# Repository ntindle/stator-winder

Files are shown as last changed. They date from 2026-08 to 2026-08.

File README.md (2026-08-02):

# Stator Winder

Parametric CAD, simulation, and validation tooling for a four-axis flyer
winding machine for small BLDC stators.

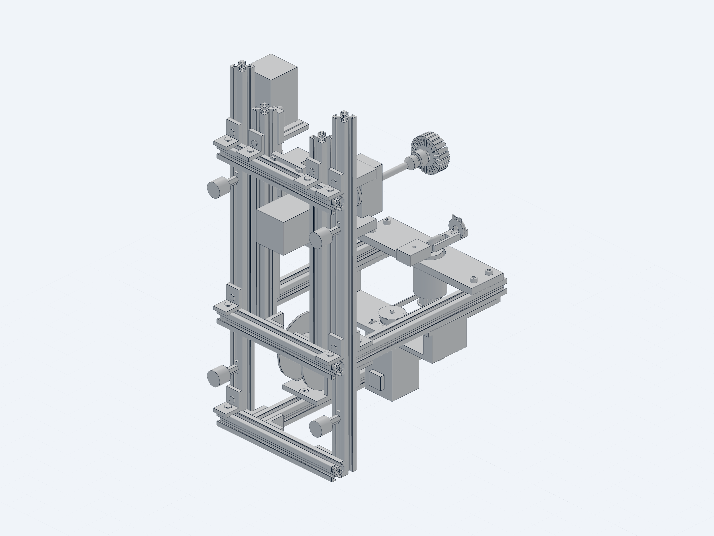
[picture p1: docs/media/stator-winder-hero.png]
Stator winder reference assembly


> [!WARNING]
> This is an engineering research prototype, not a production-ready machine.
> It has not completed physical winding, endurance, electrical-safety, or
> operator-safety qualification. The current release logic intentionally keeps
> hardware motion fail-closed.

The project models the complete mechanism in Python, derives controller
settings from the geometry, captures the real controller's motion contract,
and audits collisions, wire routing, loads, printability, and procurement
readiness before hardware is purchased.

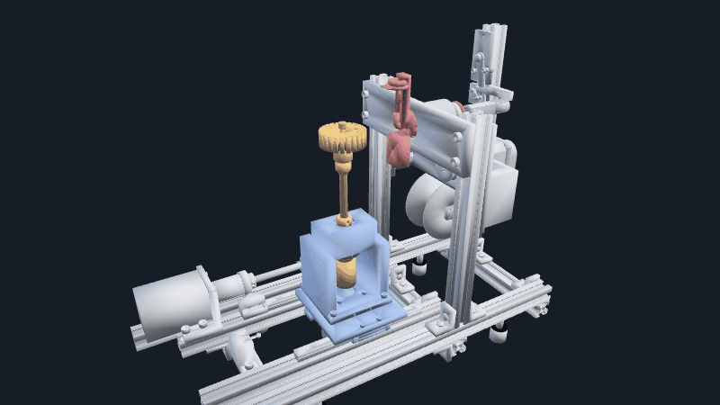
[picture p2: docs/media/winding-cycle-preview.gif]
Simulated winding-cycle preview


_Generated from the captured upstream-motion simulation. This is a mechanism
visualization, not physical-process or production evidence._

<p align="center">
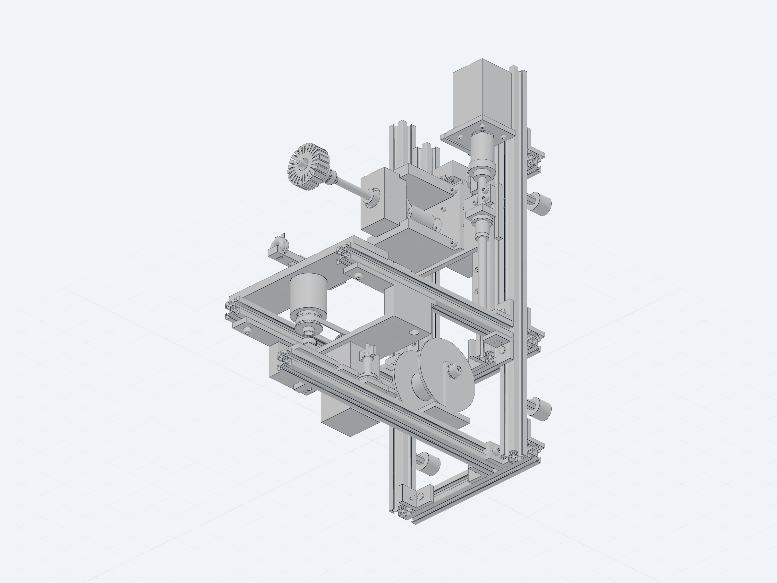
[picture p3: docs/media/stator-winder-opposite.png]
Stator winder drive-side assembly view
  
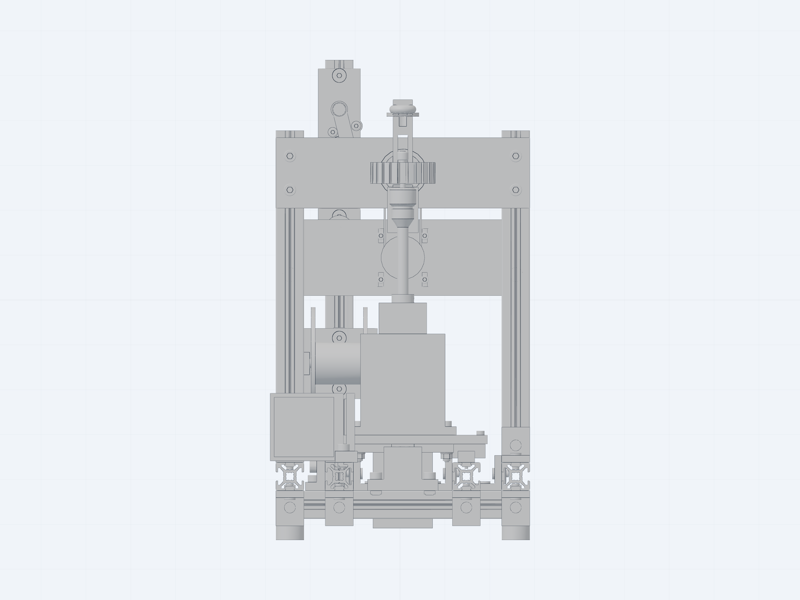
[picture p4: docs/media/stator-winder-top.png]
Stator winder top assembly view
  
</p>

_High-resolution views of the redistributable reference assembly. Purchased
components use project-authored dimensional envelopes._

## Project status

- Parametric machine, tooling, and fixture source is present.
- The controller protocol and upstream motion sequence are captured and tested.
- Extensive rigid-body, conductor-path, manufacturing, and procurement audits
  are implemented.
- The selected rigid geometry has useful simulation evidence, but the complete
  moving conductor path and physical process are not yet qualified.
- The launch matrix remains **0/24 production-authorized configurations**.
- No claim is made that this design is safe to build or operate without an
  independent engineering and safety review.

The detailed working state lives in
[`docs/engineering-status.md`](docs/engineering-status.md), and open release
work is tracked in [`TODO.md`](TODO.md).

## Download and build

The public [`hardware/`](hardware/) package contains a vendor-free reference
assembly, 21 print-oriented STL files with editable STEP counterparts, custom
machining STEP files, the carriage DXF, shop drawings, proof coupon, and order
CSVs. Start with the [`builder guide`](BUILD.md) and review the explicitly
incomplete [`cost status`](COSTS.md) before ordering anything.

The loadable assembly uses project-authored dimensional envelopes for
purchased components. Exact supplier CAD remains optional local verification
material and is not redistributed without a clear license grant.

## Architecture

| Axis | Role | Current mechanical approach |
| --- | --- | --- |
| M0 | Stator carriage | Dual MGN12 rails and a T8x8 lead screw |
| M1 | Stator index | Direct-drive, continuously rotating workholder |
| M2 | Flyer | Belt-driven hollow shaft, balanced arm, and wire guide |
| M3 | Tension | Passive felt drag and spring dancer; motor mount reserved |

The default verification envelope covers 28–65 mm stator OD, 5–20 mm stack
height, 3–8 mm shafts, and 0.20–0.50 mm magnet wire. Those are modeling inputs,
not qualified production limits.

The machine is designed around the command and motion contract of
[`aotenjo-xyz/winder`](https://github.com/aotenjo-xyz/winder). That MIT-licensed
project remains a separate dependency and is not copied into this repository.
The project-owned adapter is deliberately narrow and preserves the upstream
serial protocol.

## Repository map

```text
cad/          parametric mechanism, parts, drawings, and CAD audits
controller/   fail-closed entry point around the separate upstream controller
docs/         requirements, engineering status, and RFQ material
hardware/     loadable alpha build package containing project-owned artifacts
print/        proof-coupon and slicer-profile tooling
sim/          capture, kinematics, collision, conductor, and release audits
bom.csv       purchasing candidates and qualification state
TODO.md       open engineering and release blockers
```

Selected project-owned build artifacts are tracked under `hardware/`. The
broader generated audit tree and locally downloaded supplier models remain
untracked; they are either reproducible evidence or externally controlled
reference assets rather than project source.

## Quick start

Python 3.11 is the currently verified runtime. On Windows PowerShell:

```powershell
git clone https://github.com/ntindle/stator-winder.git
git clone https://github.com/aotenjo-xyz/winder.git
Set-Location stator-winder
py -3.11 -m venv .venv
.venv\Scripts\python.exe -m pip install -r requirements-dev.txt
.venv\Scripts\python.exe -m playwright install chromium
.venv\Scripts\python.exe cad\settings_gen.py --spindle er11
.venv\Scripts\python.exe cad\assembly.py `
  --reference-mode envelope `
  --output out\stator_winder_reference_envelope.step
```

Keep the two checkouts as siblings, or pass `--winder` explicitly to
`controller/run.py` and `sim/capture.py`.

Run the source-only smoke checks:

```powershell
.venv\Scripts\python.exe -m unittest discover -s sim -p "test_controller_adapter.py"
.venv\Scripts\python.exe -m unittest discover -s cad -p "test_settings_gen.py"
.venv\Scripts\python.exe -m unittest discover -s cad -p "test_public_reference_envelopes.py"
```

Many geometry and release tests require supplier CAD cached under
`cad/models/`. Those files are intentionally not redistributed here. See
[`cad/models/README.md`](cad/models/README.md) and the adjacent provenance
reports before running the full suite.

The source-only reference assembly and packaged manufacturing artifacts do not
require that optional exact-model cache.

## Typical workflow

```powershell
# Generate settings from the current geometry
.venv\Scripts\python.exe cad\settings_gen.py --spindle er11

# Export the vendor-free reference assembly and collision links
.venv\Scripts\python.exe cad\assembly.py `
  --reference-mode envelope `
  --output out\stator_winder_reference_envelope.step
.venv\Scripts\python.exe cad\export_links.py --spindle er11

# Optional: with the separately obtained exact supplier-model cache
.venv\Scripts\python.exe cad\assembly.py --reference-mode exact

# Capture the untouched upstream motion stream
.venv\Scripts\python.exe sim\capture.py `
  --controller upstream `
  --settings out\settings.yml `
  -o out\capture\upstream_current_raw.jsonl

# Reconstruct and audit it
.venv\Scripts\python.exe sim\verify_cycle.py `
  --capture out\capture\upstream_current_raw.jsonl `
  --report out\reports\upstream_current_raw_cycle.json `
  --expect-controller upstream
.venv\Scripts\python.exe sim\collide.py `
  --workers 1 `
  --capture out\capture\upstream_current_raw.jsonl `
  --output out\reports\clearance_upstream_raw.json
.venv\Scripts\python.exe sim\wirepath.py `
  --capture out\capture\upstream_current_raw.jsonl `
  --output out\reports\wirepath_upstream_raw.json
```

Several release commands are expected to return nonzero while a safety or
evidence gate remains open. A nonzero result must not be bypassed merely to
produce a green report.

## Origin and third-party material

The mechanical source in this repository was independently parameterized from
the project's requirements. Publicly visible product photos, documentation,
patent publications, and conventional flyer-winder architecture were used to
understand function and failure modes; their images and geometry are not
included.

The separate Aotenjo controller established the compatibility contract. COTS
dimensions and locally cached supplier models were used for fit and collision
work. Because several of those downloads have vendor-only or unclear
redistribution terms, the public source tree excludes all supplier CAD,
datasheets, product photos, converted previews, and community models.

See [`PROVENANCE.md`](PROVENANCE.md) and [`NOTICE.md`](NOTICE.md) for the exact
boundary. Licensing a repository does not grant rights in third-party patents,
trademarks, reference media, or supplier CAD.

## Licensing

- Project software and documentation: [MIT](LICENSE)
- Original mechanical design source: your choice of MIT or
  [CERN-OHL-P-2.0](LICENSES/CERN-OHL-P-2.0.txt)
- Third-party dependencies and locally cached reference assets: their own
  terms; they are not covered by the project license and are not included in
  the public source snapshot

The precise file-scope rules are in [`LICENSES/README.md`](LICENSES/README.md).

Copyright 2026 Nicholas Tindle.

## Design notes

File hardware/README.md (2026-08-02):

# Hardware build package

Everything under this directory is project-authored output selected for the
public alpha build package. It is covered by the repository's mechanical
design license scope in [`../LICENSES/README.md`](../LICENSES/README.md).

The package deliberately contains no supplier or community CAD. Purchased
components in the reference assembly are project-authored dimensional
envelopes. See [`manifests/external-cad.json`](manifests/external-cad.json) for
the optional exact-model cache boundary and [`../BUILD.md`](../BUILD.md) for
the build workflow.

`manifests/build-package.json` records a SHA-256 checksum, size, category, and
source path for every generated artifact in this package.

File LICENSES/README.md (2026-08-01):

# License scope

Copyright 2026 Nicholas Tindle.

This repository uses established licenses without custom license clauses.

## Software and documentation

Project-authored software, tests, configuration, reports, and documentation are
licensed under the [MIT License](../LICENSE).

SPDX expression: `MIT`

## Original mechanical design source

Project-authored mechanical design source—including the Python CAD under
`cad/`, print tooling under `print/`, fabrication descriptions, and original
generated design outputs—is dual-licensed. You may use it under either:

- the [MIT License](../LICENSE); or
- the [CERN Open Hardware Licence Version 2 - Permissive](CERN-OHL-P-2.0.txt).

SPDX expression: `MIT OR CERN-OHL-P-2.0`

The CERN license is particularly suited to making and sharing physical
products from design source. The copy in this repository is the unmodified
definitive CERN-OHL-P-2.0 text.

## Third-party material

Third-party dependencies and locally cached reference files are governed by
their own terms and are not covered by either project license. The intended
public source snapshot excludes supplier CAD, datasheets, product media,
archives, and unlicensed community models. See [`NOTICE.md`](../NOTICE.md) and
[`PROVENANCE.md`](../PROVENANCE.md).

If a third-party artifact is present in a local working copy, its presence does
not make it MIT- or CERN-OHL-licensed.

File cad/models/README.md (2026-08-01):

# External CAD cache

This directory is a local cache boundary, not a redistributable model library.

The project uses exact supplier and catalog models for interface checks where
their geometry materially affects fit or collision results. Most of those
files do not carry an open redistribution license. They are therefore ignored
by Git and must be obtained directly by each user under the source's current
terms.

The project-authored Python generators, JSON provenance manifests, and Markdown
verification reports remain versioned. Consult `upgrades/*.report.md`,
`upgrades/*.source.json`, `bom.csv`, and `NOTICE.md` for:

- expected local filename;
- supplier and exact part number;
- source URL;
- known license or terms boundary;
- authoritative interface dimensions; and
- SHA-256 checksum where one was recorded.

Do not substitute a similarly named model without rerunning the dimensional,
placement, collision, and load audits that depend on it.

The absence of a supplier file should fail the exact-model audit or select an
explicit parametric-envelope path. It must never silently create a claim that
the exact purchased component was verified.

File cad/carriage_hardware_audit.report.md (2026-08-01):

# Carriage hardware audit — Goal 1

Date: 2026-07-10  
Scope: MIC6 carriage plate, MGN12H block fasteners, spindle tower, M1 motor,
T8 nut/bracket, rear endstop flag, and the M0 fixed-end support.

## Result

The isolated corrected candidates pass all eight deterministic tests.  Four
real positive-volume faults were reproduced and removed.  The M1 motor stack
was also checked explicitly and is already correct: the current two-millimetre
underside pocket leaves a four-millimetre printed roof under all four heads.

| source-level Boolean check | measured pre-fix | corrected candidate |
|---|---:|---:|
| four inner MGN12H M3 heads vs spindle tower | 275.158 mm³ | 0.000 mm³ |
| rear flag M4 washers/nylocs vs printable flag | 294.614 mm³ | 0.000 mm³ |
| lower two T8 washer/nyloc stacks vs bracket foot | 79.108 mm³ | 0.000 mm³ |
| printable flag vs M0 fixed-end mount | 12.000 mm³ | 0.000 mm³ |
| M1 head-bearing material, four 0.10 mm annular probes | 6.504 mm³ | 6.504 mm³ |

Run:

```powershell
.\.venv\Scripts\python.exe cad\test_carriage_hardware_audit.py
```

Observed: `Ran 8 tests ... OK`.

## Exact shared patch table

1. `cad/printed.py:spindle_tower`

   Subtract four axis-Y cylinders, Ø6.4 and 3.25 mm deep from the MIC6 mating
   face, at machine X/Z `(-35,85)`, `(-35,105)`, `(35,85)`, `(35,105)`.
   Start the overshooting tools at `plate_top_y - 0.5`.  The ISO 4762 M3 head
   is Ø5.68 x 3.00, so this provides 0.36 mm radial print allowance and leaves
   a 2.75 mm roof, above the 2.4 mm minimum wall.  Keep all eight M3x10 block
   screws.  Do not countersink the MIC6 plate.

2. `cad/printed.py:nut_bracket`

   Replace the current full-width 8 mm foot with:

   - a 2.4 mm-high web at `x=-84..-60`, `y=plate_top..plate_top+2.4`,
     `z=85..109`;
   - an 8 mm-high local M4 bearing rail at `x=-84..-72`,
     `y=plate_top..plate_top+8`, `z=92..112`;
   - Ø7.2 access channels through only the web, `z=85..92`, centered on the
     T8 flange's 225° and 315° holes.

   Keep the main T8 wall at `z=77..85` and its four Ø3.2 through-holes.  This
   gives every washer a full bearing face while clearing the two lower nylocs.

3. `cad/printed.py:m0_fixed_end_mount`

   Trim the support foot's X maximum from `-35` to `-38`.  This gives the
   moving flag 2.0 mm lateral clearance at every M0 pose.  The M5 center at
   `x=-45` retains a 4.3 mm edge ligament outside its Ø5.4 clearance hole.

4. `cad/hardware_placements.py:carriage_occurrences`

   Split front/rear tower under-head stack datums:

   - front row (`z=64`): washer `y=plate_bottom=-192.00`, nyloc `y=-192.90`;
   - rear row (`z=126`): washer `y=FLAG_BOTTOM_Y=-198.00`, nyloc `y=-198.90`.

   Keep ISO 4762 M4x20 at the front and M4x25 at the rear.  After the ISO 7089
   0.9 mm washer and ISO 10511 5.0 mm nyloc, visible thread is 1.75 mm front
   and 0.75 mm rear.

5. `cad/hardware.py` and `cad/hardware_placements.py`

   Change the four T8 flange screws from ISO 4762 M3x16 to M3x18.  Keep head
   plane `z=73.2`, set washer plane `z=85.0`, and set nyloc start `z=85.55`.
   The stack is 3.8 mm flange + 8.0 mm printed wall + 0.55 mm washer + 4.0 mm
   nyloc = 16.35 mm, leaving 1.65 mm visible thread.  The tip ends at `z=91.2`,
   0.8 mm before the local M4 rail begins.

No shared patch is required for M1: keep ISO 4762 M3x10 x4, head plane
`y=-179.65`.  The existing four-millimetre roof leaves 6.0 mm thread
engagement in the motor.

## SendCutSend and datum preservation

The MIC6 source, 1:1 DXF, outer contour, 14 round holes, motor window, and T8
relief remain byte-for-byte eligible for the existing through-cut preflight.
No countersink, counterbore, tapping, or second-side machining is introduced.
Measured plate volume remains 61,747.022181 mm³ in 6.35 mm ALUMIC6-250.

The stator/spindle datum is unchanged: axis `X=0`, home `Z=95`; MIC6 bottom
`Y=-192.00`, top `Y=-185.65`.  No bearing seat, tower M4 coordinate, motor
face, or MGN12H coordinate moves.

## Intended-contact and dynamic-fit mapping

The following relationships must be whitelisted as documented fits/contacts,
not ignored generically:

| pair/stack | intent |
|---|---|
| plate / tower | printed tower seats on MIC6 top face |
| plate / rear flag | flag seats on MIC6 bottom face |
| MGN screw / plate / tapped block | head bearing, clearance pass, 3.65 mm engagement |
| tower screw / tower / plate [/ flag] / washer / nyloc | complete front/rear clamp stack |
| bracket M4x25 / local rail / plate / washer / nyloc | complete bracket clamp stack |
| T8 M3x18 / flange / wall / washer / nyloc | four equivalent, wrench-accessible stacks |
| M1 M3x10 / four-millimetre roof / motor | head bearing plus 6.0 mm tapped engagement |
| inner-race spacer / outer-race spacer | explicit dynamic fit exemption; 0.20 mm concentric radial clearance, zero positive-volume overlap |
| lower inner spacer / lower DIN 472 ring | explicit dynamic fit exemption; about 0.60 mm concentric radial clearance, zero positive-volume overlap |

The last two exemptions are appropriate because the general 2 mm dynamic
clearance policy cannot apply across a bearing race stack.  They should remain
conditional on a zero-positive-volume Boolean check; do not make a blanket
spindle/carriage exemption.

## Artifact note

This work adds an inspection module, tests, and this report only.  It does not
export or modify a primary STEP, so CAD snapshot/viewer handoff is intentionally
deferred to the production assembly regeneration after the shared patch is
applied.

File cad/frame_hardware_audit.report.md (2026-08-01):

# Static frame hardware source-BREP audit

OpenCascade common-volume booleans on the authored build123d solids; STL/FCL meshes are not used.

## production 15-HBKT plus custom-shoe layout (bracket bodies)

- Brackets: 15
- Broad-phase candidate pairs: 5
- Positive-volume pairs: 0
- Allowed thread/T-slot engagements: 0
- Forbidden collisions: 0

## independently normalized 15-HBKT plus custom-shoe layout (HBKT bodies)

- Brackets: 15
- Broad-phase candidate pairs: 5
- Positive-volume pairs: 0
- Allowed thread/T-slot engagements: 0
- Forbidden collisions: 0

## Custom rear-post left shoe

- Shoe/cross common volume: 0.000000 mm3
- Shoe/post common volume: 0.000000 mm3
- Gap to left base rail: 1.000000 mm
- Nearest repositioned HBKT gap: 1.000000 mm
- Floor bore minimum ligament: 3.300 mm
- Upright bore minimum ligament: 5.300 mm
- Floor head minimum edge margin: 1.640 mm
- Upright head minimum edge margin: 3.640 mm
- Scallop back wall: 3.400 mm
- Scallop-to-upright-bore ligament: 2.500 mm
- Forbidden positive-volume pairs: 0

Allowed positive volumes are limited to the documented T-slot envelope:

- `rear_post_left_shoe_floor_m5x12` / `cross_rear`: 8.329693 mm3, `tslot_passage_envelope`
- `rear_post_left_shoe_floor_tnut` / `cross_rear`: 141.887304 mm3, `tslot_capture`
- `rear_post_left_shoe_upright_m5x12` / `rear_post`: 8.329693 mm3, `tslot_passage_envelope`
- `rear_post_left_shoe_upright_tnut` / `rear_post`: 40.200000 mm3, `tslot_capture`

## Exact disposition

- Replace `frame_bracket_rear_post_left` and its four stack occurrences with the custom 14 mm-floor shoe and two M5x12/HNTA5-5 stacks. A 25 mm HBKT leg cannot fit the 15 mm X corridor.
- The requested shoe fastener centers initially failed: floor screw / upright shoe = 62.827142 mm3 and the two screw envelopes = 12.713730 mm3. Add the OD9.2 scallop y=-219.2..-213.2 and move the upright axis-X stack from y=-211 to y=-208.
- Reposition `rear_base_L`, `mid_base_L/R`, and `front_base_L/R` to their cross front faces/upper-member undersides with `x=(1,0,0), y=(0,0,1), z=(0,-1,0)`.
- Reposition `front_stringer_L/R` the same way at origins `(-45,-225,170)` and `(45,-225,170)`.
- The proposed 16th front-Z rear-post HBKT is rejected: exact common volume with the rear post is 1810.303324 mm3.
- `post_L_front` / T8 has zero common volume. It is a tangent manufacturing-risk contact, not an allowed engagement; add a 2 mm corner relief if tolerance clearance is required.

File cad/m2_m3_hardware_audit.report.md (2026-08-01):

# M2/M3 source-level hardware audit

Scope: current build123d/OpenCascade solids from `printed.py`, `cots.py`,
`hardware.py`, and `hardware_placements.py`.  The audit is isolated and does
not modify shared machine geometry.  It samples the dancer from -3.0 to +5.5
degrees at 0.25 degree increments and checks candidate repairs with exact BREP
Boolean intersections.

Result: **62/62 exact checks pass**.  Audit regression tests: **7/7 pass**
(**26/26** in the focused flyer/hardware suite).
Machine-readable evidence is generated at
`out/reports/m2_m3_hardware_audit.json`.

## Required shared-source patches

1. **M2 mount low-head access** (`printed.m2_motor_mount`)
   - Current left/right low M5x12 heads each embed in the join block by
     236.1413 mm3; the high pair is clear.
   - Subtract two OD10 axial tool/head tunnels at x=+-80, y=-72,
     z=-103..-66.  The z=-66 end is the existing screw bearing plane.
   - Candidate overlap is 0 for all four screws, the mount remains one solid,
     and 5363.81 mm3 is removed.

2. **Flush all eight rear-post base screws** (`printed` + hardware schedule)
   - Replace the spool/felt/dancer/entry M5x12 socket heads with ISO 10642
     M5x12 countersunk screws at the same axes and top plane z=-164.
   - Add OD10/OD5.4, 90 degree countersinks, depth 2.3, to all eight base
     holes.  This uniform choice avoids four separate head-access rules.
   - Current dancer-head/arm overlap reaches 128.157 mm3.  One entry head
     reaches 35.739 mm3.  Felt heads overlap each OD20 backing/pad stack by
     55.734 mm3 per side and also intersect the printed boss.
   - Candidate overlap is zero.  Dancer arm axial clearance is at least
     1.000 mm throughout the complete stop range; stop axes do not move.

3. **Entry lower-right moving-stack relief** (`printed.entry_bracket`)
   - Subtract the box x=-38.5..-27, y=-22..-7, z=-171..-163.5.
   - Current moving pulley nyloc overlap is 5.5423 mm3 and the last three
     rear shims each overlap by 1.4874 mm3.  The candidate has zero overlap;
     minimum repaired gaps are 2.7447 mm for the nyloc and 2.2655 mm for the
     shims.
   - The bracket remains one solid; 255.001 mm3 is removed.  The wire passage,
     fixed spring bridge, base screw axes, and both dancer stop centers remain
     unchanged.

4. **Flush moving spring-anchor head** (`printed.dancer_arm` + schedule)
   - Current M2x16 socket head overlaps the entry base by 10.4331 mm3.
   - Replace it with ISO 14581 M2x16 and cut an OD4.8/OD2.4 90 degree rear
     countersink, 1.2 mm deep, top plane z=-163, on the existing moving-anchor
     axis.  The 2.5 mm arm retains a 1.3 mm floor.
   - Candidate screw/arm overlap is zero, the arm remains one solid, and its
     minimum entry-bracket gap is 1.000 mm across the full sweep.

5. **M2 internal running clearances** (`assembly`/`printed`)
   - Change the outer-race spacer ID20 to ID22 while retaining OD27.8 and
     length 11.  Exact inner/outer-spacer gap rises from 1.000 to 2.000 mm.
   - Change the flyer-block through-running bore from OD25 to OD26.  Exact
     block clearances become: pulley 2.500 mm, pulley heat-set insert
     2.240 mm, pulley M3 screw 2.428 mm.
   - These are rotating clearances, not intended-contact whitelist pairs.

6. **Felt stud usable thread** (`hardware` + placement)
   - Replace M4x50 with M4x55, same rear datum z=-170.
   - Current thread is only 0.0867 mm proud of the wingnut; candidate is
     5.0867 mm proud.
   - Candidate clearance is 3.400 mm to the conservative OD2 wire model and
     37.779 mm to the exact belt solid.

7. **Counterweight clamp stack** (`hardware_placements`)
   - The three 0.55 mm M3 washers contact each other exactly, but the screw
     bearing plane is 0.55 mm ahead of the stack (exact solid distance
     0.3706 mm because of the head edge).
   - Move only the M3x12 screw origin from z=-11.8 to z=-12.35.  The candidate
     washer/head contact is zero-gap and zero-volume.

8. **Counterweight structural attachment** (`printed.flyer_arm`)
   - The old boss/collar joint had 0.000 mm3 volumetric overlap and depended
     on one coincident rear face.  The two Ø3.3 holes at x=+-6, y=-32 were
     unloaded trim bores, not fasteners, and made the attachment ambiguous.
   - Both trim bores are removed.  An integral PETG web spans x=+-7,
     y=-25..-8.45, z=-28.8..-20.  Exact overlap is 55.357 mm3 into the hub
     collar and 1643.683 mm3 into the counterweight boss; the finished flyer
     arm remains one solid.
   - The web stays 2.400 mm outside the Ø12.1 shaft passage, has 2.200 mm
     clearance to the stationary flyer block, and the complete rotating arm
     retains its existing 2.000 mm minimum block clearance.
   - The one real counterweight axis remains x=0, y=-25.  The M3 screw spans
     the full 4.300 mm McMaster 94459A130 insert; its intended heat-set
     interference is 4.210 mm3.  The three washers are the only tuning stack.
   - The solid boss outer radius is 42.4 mm, still inside the tip-guide sweep.
     Integrated balance is -0.5 g-mm residual (0.00 N rounded at 300 RPM);
     M2 simulation-duty torque margin remains 2.36x.

## Verified stacks and intended contacts

- Spool: OD8 axle has positive clearance through bracket and drum; both
  washers seat against their ears and the right nyloc seats against its
  washer.  No geometry change is required.
- Felt: fixed backing/pad, moving pad/backing, spring/thrust washer, and
  thrust washer/wingnut are zero-gap, zero-volume contacts.  The two pads have
  a 0.500 mm rigid-model wire gap.
- Flyer heat-set inserts: positive overlap is intentional plastic
  displacement, not a collision.  Exact embeds are 5.5953 mm3 for each arm
  insert, 15.7158 mm3 for the pulley insert, and 4.2102 mm3 for the
  counterweight insert.
- Screw shanks in clearance holes must have zero positive volume.  Threaded
  screw/nut or screw/insert pairs may be tangent in the simplified BREP.
- Screw-head/washer bearing interfaces must be zero-gap and zero-volume.
- Dancer stop sleeve/arm contact is allowed only at the specified -3.0 and
  +5.5 degree endpoints; no positive-volume embedding is allowed.
- Inner/outer M2 spacers and flyer clamp hardware/flyer block are running
  clearance pairs and must not be added to an intended-contact whitelist.

All added material is localized to the counterweight web/boss and was checked
explicitly against the shaft passage, stationary flyer block, and rotating
envelope.  The longer felt stud was also checked explicitly as reported above.

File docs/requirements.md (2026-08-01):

# Derived Requirements — 4-Axis Stator Flyer Winder

Source of truth: `winder` repo @ `6039b33` (2026-06-13), read in full. This sheet is derived from
`src/winding.py`, `src/position.py`, `src/utils.py`, `src/constants.py`, `scripts/main.py`,
`scripts/ws.py`, `simulation/node_3d.gd`, `settings-example.yml`, `tests/dev-*.yml`.
GOAL.md is the parent spec. **The software is the fixed contract; geometry must serve it.**

## 1. Protocol contract (serial, host → controller)

| Command | Meaning |
|---|---|
| `M{id}A{value}\n` | Absolute position target, **radians**, float rounded to 3 decimals. Fire-and-forget (no ack; host paces with `sleep()` and position polling). |
| `M{id}P\n` | Position query → response `M{id}P{value}` (radians). Host busy-polls M2 during winding (~30 Hz). |
| `ESTOP\n` | Stop all motors. |

Sent value = model-space target × `direction` sign (per-axis bool in settings) × `m2_gear_ratio`
(M2 only; code constant in `src/constants.py`, currently 50/50 = 1.0 — **not** in settings.yml).
Motion model assumed by the software's own simulator: constant-velocity slew toward target at the
per-axis `velocity` (rad/s) from settings; no acceleration model. Firmware must track **multi-turn
absolute position** on M1 and M2 (M2 accumulates roughly ±7,600 rad over one full 24-slot 50-turn cycle;
M1 zero drifts cumulatively via shaft wraps).

## 2. Kinematic architecture (confirmed by Godot scene mapping)

Machine frame: **Z** = flyer rotation axis (horizontal), **Y** = up.

- **M0 (linear):** translates the stator carriage (with M1 unit) along Z. Godot: `stator.position.z = −M0 + const`.
- **M1 (rotary):** rotates the stator about the **vertical Y axis** — stator shaft is held vertical,
  one tooth points horizontally along Z toward the flyer. Godot: `stator.rotation.y = −M1 + π/2`.
  Unlimited rotation both directions (no cables to the rotating side).
- **M2 (rotary, continuous):** flyer arm spins about Z, coaxial with M0 travel. Godot: `arm.rotation.z = M2`.
  Wire enters through hollow shaft from rear (−Z side), exits at tip eyelet.
- **M3 (torque):** wire tension between spool and hollow shaft. Values are normalized torque
  (`wind_torque: 0.04`, `pull_wire_torque: 0.15`), voltage-mode. `dont_move_m3: true` supported →
  passive tensioner is legitimate for v1.

Winding geometry: the presented tooth's radial axis is parallel to Z; the flyer wraps wire around
the tooth neck; M0 traverse during winding spreads turns **along the tooth length** (radial
direction of the stator), not along stack height.

## 3. M0 coordinate semantics (settings.yml quirks included)

Upstream example values (radians): `wind_range_start=−25.5 < wind_range_end=−14.0` <
rotating `=end+6.0=−8.0` < init zero `=end+9.0=−5.0` < home `0`.

- **More negative = deeper insertion toward/through the flyer plane. Home (absolute 0) = fully retracted = load/unload pose.**
- `m0_zero = M0.end_to_zero + wind_range_end` (init pose after `init_position()`).
- Rotating position `= M1.end_to_rotating_position + wind_range_end` — **note: this key lives under
  the `M1:` section of settings.yml even though it is an M0 target.** The settings generator must respect this.
- During a winding pass M0 slews `start → end → start` once (ease-out-sine on M2 progress,
  re-targeted every π of M2 travel). `ease-out-sine` path has **no range clamp** in
  `position.py` — generated ranges must be self-consistent (`start < end`).
- Transmission ratio (rad→mm) is ours to define and document. Baseline: T8×8 lead screw ⇒
  **1.2732 mm/rad** (upstream's numbers are consistent with this: wind range 11.5 rad ≈ 14.6 mm,
  home-to-wind-end 14 rad ≈ 17.8 mm, indexing retract 6 rad ≈ 7.6 mm).

## 4. M1 / M2 motion semantics the mechanism must survive

- Tooth indexing: `M1 = m1_zero − idx·(2π/N)` (counter-clockwise tooth order), N = slot count (12/24/36 supported today).
- Shaft wrap (`wind_wire_around_shaft`, between each of the 3 phases): current upstream applies an
  **absolute** M1 target derived from `m1_zero`, then permanently mutates `m1_zero` and `m2_zero`.
  From the actual indexed starting poses in the canonical 24-slot raw capture, the completed
  physical deltas are **1.375000 turns** and **2.791667 turns**, not two and two.  The digital twin
  must reproduce those exact raw deltas as evidence, and the mechanism must clear their complete
  swept envelope, but that does **not** make them acceptable winding motion: parent `GOAL.md`
  explicitly requires two full turns at each inter-phase maneuver.  An independent settings and
  fixed-transmission proof shows neither can map both raw deltas to two physical chuck turns while
  preserving 24-slot indexing.  Normal-GOAL release therefore remains fail-closed until an
  unmodified upstream revision restores a relative `current_position ± 4π` target (or the user
  explicitly changes the software-contract authority).
- Flyer parking state machine (`Motor2State`): TOP (12 o'clock), BOTTOM (6 o'clock), each ±
  `angle_to_prevent_collision` (1.0 rad ≈ 57.3° in every shipped config). All six park states occur.
- One winding pass = `turns` (50 in the current default and raw capture) full revolutions + up to 1.5 extra revs for entry/exit
  repositioning (±π wire-side flips, ±1–2 rad park offsets).

## 5. Collision-critical poses (drives the interference test matrix)

1. **Indexing:** M0 at rotating position (stator retracted only ~7.6 mm behind wind-end), M1
   sweeping up to 2π, flyer parked at any of the 6 park states. Rotating stator teeth + shaft stub
   vs. parked arm, eyelet, and wire run.
2. **Wire-side flip, stator partially inserted:** `set_motor2_wire_position()` rotates M2 up to
   2.0 rad with M0 at `wind_range_end`.
3. **Post-pass park, stator fully inserted:** `prevent_collision()` rotates M2 ±1.0 rad with M0
   still at `wind_range_start` (deepest).
4. **`move_wire_to_right_position()` (fires at tooth 16 of 24n22p):** M2 sweeps **π + 1.0 rad with
   the stator fully inserted** at `wind_range_start`. Strongest flyer-vs-stator clearance case.
5. **Shaft wrap:** M0 at rotating position and flyer at TOP ±1 rad.  Collision coverage includes
   both the intended two-full-turn maneuver and the larger current raw 2.791667-turn sweep; the
   wire path from eyelet down to the shaft must clear the arm and chuck throughout.  Passing this
   mechanical envelope cannot waive the separate upstream command-stream failure.
6. **Full winding sweep:** flyer 360° swept volume vs. inserted stator (all M0 wind-range depths),
   chuck body below the stator, and carriage/frame. The chuck column below the stator sits inside
   the flyer's swept cylinder region — arm reach/shape and tip circle must be proven against the
   chuck at max stator OD and min chuck standoff.
7. **Load/unload:** all axes at absolute 0 (`back_to_zero()`), operator access to the chuck.
8. Winding start from 6 o'clock (`starts_at≠0` restart path): M2 moves π from zero with M0 at init zero.

## 6. Velocity / duty data (motor sizing inputs)

| Axis | Config velocity | Peak in cycle | Notes |
|---|---|---|---|
| M0 | **20 rad/s** generated | 20 rad/s ≈ 25.5 mm/s | Settings-only timing fix; reaches deep winding start before the first raw M2 command |
| M1 | **20 rad/s** generated | 20 rad/s | Reaches both current raw absolute targets inside 1.5 s; a corrected two-turn relative target would finish in 0.628319 s. Velocity changes timing only and cannot repair the wrong raw displacement. |
| M2 | 20 rad/s | 20 rad/s = **191 RPM** | `fast_winding` commands ~10.5 rad/s (≈100 RPM), then a single long move runs at the 20 rad/s cap. Design target **≥ 300 RPM (31.4 rad/s)** per GOAL. |
| M3 | torque mode | 0.04–0.15 norm. | Passive in v1 (`dont_move_m3`) |

## 7. Digital-twin fidelity requirements

- Drive the **unmodified** software (`scripts/main.py -s` piped, or `Wind(cfg, simulation=True).continuous_winding()`)
  and capture the command stream via `WINDER_LOG_LEVEL=DEBUG` (env override built into `utils.init_logger`) —
  every `move_motor` logs the exact serial command with a millisecond timestamp.
- Twin must replicate: constant-velocity slew model, `m1_zero`/`m2_zero` drift, Motor2State ±offsets,
  and the M0↔M2 coupled traverse. Official validation run uses **real sleeps** (unmodified timing);
  iteration runs may cap `sleep` at 0.35 s exactly as the repo's own test suite does.
- `scripts/ws.py` hardcodes `settings.yml` in CWD and streams 60 fps interpolated positions —
  our generated settings.yml must also live at repo root for the Godot/WebSocket path to work.

## 8. Flags / contradictions vs GOAL.md

1. **Shaft-wrap contradiction -- release blocker:** GOAL and the code comment require two physical
   M1 turns, but untouched upstream `6039b33` completes 1.375000 and 2.791667 turns.  The regression
   entered at upstream `8e7904a`.  Zero, direction, velocity, `starts_at`, M0/M2 settings, all 48
   canonical electrical pattern equivalents, and any one fixed affine M1 transmission have been
   exhausted; none can make both maneuvers two turns without also breaking tooth indexing.  The
   twin reproduces the stream and geometry is validated against its larger sweep, but normal-GOAL
   DoD remains **FAIL_CLOSED**.  No adapter or local upstream patch is applied.  The smallest
   documented upstream correction is to command the queried live M1 position ± 4π.
2. **Layering limitation, not a software-contract contradiction:** untouched upstream hard-codes
   `ease-out-sine`.  With the current linear T8 transmission it matches the deterministic
   diagnostic honeycomb schedule only 6/2400 placement states and contains zero/sub-wire-diameter
   radial pitch near the traverse reversals.  That means the simulator cannot claim exact layer
   order or neatness; `GOAL.md` explicitly leaves those tension/contact outcomes to hardware
   qualification.  It does **not** by itself require a synchronized guide or nonlinear M0
   transmission.  Production authorization still requires the raw-cycle wire path to distinguish
   intended workpiece/copper contact from steel or hardware contact and to prove a continuous
   centreline bend radius of at least 3 mm.
3. **R3 workpiece-route input gap:** tight conformity to the lined default tooth corner is only
   R0.23876 and cannot satisfy the literal 3 mm rule. Earlier retractable-shroud, R58/R64 review-arm,
   and aggregate-former studies are historical design lanes, not the selected authority. The current
   rev6 architecture uses two M0-following/M1-static active-sector PEEK guides on an outboard
   coil-bypass aluminum yoke plus rotating short-leadin PEEK caps. It passes all 2400 default-job
   terminal loci and the complete rigid raw-motion sweep, without claiming deterministic layer
   order. The flexible guide-to-workpiece conductor family between states, both exact two-turn shaft
   wraps, sag/snags/abrasion, and the 24-case launch envelope remain fail-closed. `StatorSpec` also
   does not define the finished motor's available rotor/end-bell axial cavity, so finished-motor fit
   remains a separate measured constraint.
4. GOAL says software drives ~100 RPM — true for the stepped `fast_winding` phase, but the long
   move to target runs at the **velocity cap = 191 RPM** with shipped configs. The ≥300 RPM
   mechanical target still gives ≥1.57× headroom over the cap; keep the cap in generated settings ≤ our rating/1.5.
5. GOAL describes `angle_to_prevent_collision` as clearing the flyer "during indexing" — the code
   also uses it **doubled** (wire-side flip) and combined with π **while the stator is fully
   inserted** (pose 4 above). Our clearance validation must cover those stronger cases, not just indexing.
6. `end_to_rotating_position` lives under `M1:` in settings.yml despite being an M0 target (§3) —
   generator must follow the quirk, not "fix" it.
7. `m2_gear_ratio` is a code constant, not a settings key: if our flyer is belt-driven with a
   non-1:1 ratio, the **firmware** (out of scope) or a 1:1 belt must absorb it. **Decision: design
   flyer drive as 1:1 belt** so the shipped constant stays valid.
8. Winding configs exist for 12, 24, 36 slots — mechanism must not assume 24 (index angle is 2π/N).

## 9. Fixed design decisions derived above

- M0 baseline: T8×8 lead screw (1.2732 mm/rad), MGN12 rail, home switch at retracted end,
  ~100 mm usable travel.  The rejected inverse-sine/two-track studies do not veto this direct-linear
  mapping; it remains the production candidate while the independent raw-cycle R3/contact wire-path
  gate is open.
- M1: vertical hollow-free chuck axis, motor under carriage, unlimited rotation; ER11 for measured Ø3–7 mm shafts and the separate `shaft8` socket holder only for Ø8.00 mm.
- M2: hollow-shaft flyer with selected Rev-D L79 OD10/ID6-to-OD12/ID9 shaft geometry, stock D10 NBK P30 flyer pulley, conditional D5+BNW motor P30, 210-3GT-6 belt at exact 30T:30T, and six balance trims. OD28–65 is a verification matrix (90 mm remains parametric); 0/24 launch certificates currently pass, so no envelope corner is production-authorized.
- M3: passive dancer + adjustable felt tensioner, 1–10 N, motorized-spool-ready mount, `dont_move_m3: true` in generated settings v1.

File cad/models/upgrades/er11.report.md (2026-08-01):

# ER11 C8 collet chuck — high-fidelity model upgrade report

**Part:** C8-ER11A-100L straight-shank collet chuck (Ø8 mm shank × 100 mm,
ER11-A clamping nut) + ER11 collet
**Deliverables:** `er11_c8_hifi.py`, `er11_c8_hifi.step` (this directory)
**Date:** 2026-07-08
**Replaces (envelope):** `cad/cots.py::er11_chuck_c8` — 3 stacked cylinders
(nut Ø19 × 19, head Ø18 × 16, shank Ø8 × 100, Ø8.2 bore).

---

## 1. STEP search result — no legitimate no-login file found

A downloadable STEP was searched for first:

- **TraceParts / vendor CAD:** ER11 nut and C8-ER11A holder pages exist but
  gate CAD downloads behind account login.
- **GrabCAD / 3DContentCentral:** login-walled — skipped per task.
- **GitHub CNC projects:** hits are STLs / renders, no dimensioned STEP of a
  C8-ER11A-100L holder with an ER11-A nut under a redistributable license.
- **Rego-Fix / vendor sites:** publish **dimensioned drawings** (used below)
  but not free STEP of this exact holder.

Conclusion: no legitimate no-login STEP exists for this exact SKU, so a
**high-fidelity parametric build123d model** was built from cited drawings.

---

## 2. Sources / drawings cited

| # | Source | Used for |
|---|---|---|
| S1 | Rego-Fix *ER System Product Catalog* (us.rego-fix.com RFTC_ER_Catalog) and *ER Spannzangen-Masse* technical drawing (RFAG_TD_ER…) | ER system originator; ER11 nut OD, thread, collet 8° taper geometry |
| S2 | tools-n-gizmos ER Collet Nut spec table (tools-n-gizmos.com/specs/ER_Collet_Nut.html) | ER11 nut: OD 19 mm, L ≈ 11.3–13 mm, thread M14×0.75; A vs mini distinction |
| S3 | MariTool ER11 collet nut product data (maritool.com) | ER11 nut OD 0.748″ = 19 mm, thread M14×0.75, external hex |
| S4 | HHIP / uxcell / Genmitsu / Qjaiune **ER11-A** clamping nut product data | ER11-**A** nut: OD 19 mm, **height 13 mm (19 × 13/14 D×H)**, M14×0.75, 17 mm hex |
| S5 | DIN 6499 / ISO 15488-B ER data — CGTK ER table (cgtk.co.uk/metalwork/data/er), Sikka, CNCollets, Somma (DIN 6499) | ER11 collet: OD 11.5 mm, length 18 mm, **8° taper**, thread Ø14 × 0.75, min bore length 17 mm, clamp 1–7 mm |
| S6 | Amazon / BigaMart **C8-ER11A-100L** product listings | Ø8 straight shank, 100 mm, ER11 (1–7 mm), body ≈ Ø16 behind nut |

Notes on the ER11-A nut: it is the **standard "A" (Ausführung A) nut**,
OD **19 mm**, thread **M14 × 0.75** — distinct from the **ERM11 mini** nut
(OD 16 mm, M13 × 0.75). Sources give the nut height as 11.3–14 mm; **13 mm**
(the most common ER11-A "19 × 13" D×H figure, S4) was used. The real nut has
a light hex/spanner flat for tightening; the model captures the **stepped /
waisted Ø16→Ø19→Ø16 revolved profile** (the dominant collision envelope) and
omits the shallow wrench flats (they sit inside the Ø19 max envelope).

---

## 3. Dimension table — cited vs modeled vs measured

Measured = thin-slab section of the exported STEP (build123d), printed by the
source's `__main__`.

| Feature | Cited (source) | Modeled | Measured (STEP) |
|---|---|---|---|
| ER11-A nut OD (max) | 19.0 mm (S2–S4) | Ø19.0 waisted | **19.00 mm** |
| ER11-A nut waist / collar OD | ~16 mm (Ø16–19 stepped, S1/S4) | Ø16.0 | Ø16 chamfer collars |
| ER11-A nut height | 13 mm (S4; 11.3–14 range) | 13.0 mm | z = 0 … −13 |
| Nut thread | M14 × 0.75 (S2–S5) | plain Ø14 cyl | **14.00 mm** |
| Chuck body / head OD | ~16 mm (S6) | Ø16.0 | **16.00 mm** |
| Shank OD | Ø8 h6 (S6) | Ø8.0 | **8.00 mm** |
| Shank length param | 100 mm (S6) | `shank_len=100` | tip z = **−135.00** |
| Collet OD (large end) | 11.5 mm (S5) | Ø11.5 cone | internal |
| Collet length | 18 mm (S5) | 16 mm cone | internal |
| Collet taper | 8° half-angle (S1/S5) | 8.0° cone | internal |
| Collet seat bore | Ø8.2 (project) | Ø8.2, ~25 mm deep | **8.20 mm** |

**Bounding box (measured):** X −9.50…+9.50, Y −9.50…+9.50, **Z −135.00…0.00**
(19.00 × 19.00 × 135.00 mm). Single closed solid, volume ≈ 9 978 mm³.

### Drop-in frame contract (verified)
- axis **+Z**; nut **TOP face at z = 0.000** ✓
- shank extends **−Z**, Ø8 tip at **z = −135.000** (= −(35 + shank_len)) ✓
- Ø8 shank geometry **identical below z = −35** to the crude model → the two
  608ZZ spindle bearings that grip the shank seat unchanged ✓
- overall XY/Z bounding box **identical** to the crude envelope (Ø19 × 135) ✓

### Deliberate fidelity note — the bore is a seat, not a through-bore
The task says "Ø8.2 through-bore", but a Ø8.2 (r 4.1) bore run the full length
would be **larger than the Ø8.0 (r 4.0) shank and erase the shank entirely**.
The real holder has a **solid Ø8 shank**; the Ø8.2 is the **collet seat**. So,
exactly like the crude model (whose bore was only 26 mm long), the bore stops
in the head (z = +1 … −24) and the Ø8 shank stays solid. Measured bore Ø8.20.

---

## 4. CLEARANCE-CONSTRAINT FLAG CHECK

Validated envelope constraints (from `cad/params.py`):
`chuck_nut_r = 9.5` mm, `chuck_nut_len = 19.0` mm (nut + collet nose),
`grip_gap = 3.0` mm (stator bottom face → nut top face).

| Constraint | Envelope limit | Researched / measured | Verdict |
|---|---|---|---|
| **Nut outer radius** | ≤ **9.5 mm** | **9.500 mm** (Ø19 nut) | ⚠️ **AT LIMIT — ZERO MARGIN** |
| Nut + nose axial length below stator | ~**19 mm** | **13 mm** nut, nose flush at z=0 → 13 mm (16 mm incl. 3 mm grip_gap) | ✅ PASS (6 mm spare) |

### ⚠️ FLAG — radial: nut is EXACTLY at the 9.5 mm envelope limit
The real **ER11-A nut is Ø19 mm → outer radius 9.500 mm**, which **equals**
the validated `chuck_nut_r = 9.5` mm envelope exactly. It does **not exceed**
the limit, but there is **ZERO radial clearance margin**:

- Any ER11-A nut that runs to the high side of tolerance (some are listed at
  Ø19.x mm) **would exceed** the 9.5 mm envelope and break the validated
  clearance constraint for the M1 indexing sweep.
- If more radial margin is needed, an **ERM11 mini nut (Ø16 → r 8.0 mm)**
  gives 1.5 mm; note it needs an ERM-threaded (M13 × 0.75) chuck body.
- **Recommendation:** verify the outer diameter of the actual purchased nut.
  Many economy ER11-A nuts measure Ø18 mm (r 9.0, +0.5 mm margin); premium
  balanced nuts run a full Ø19.

### ✅ Axial: better than the crude envelope
The faithful ER11-A nut is **13 mm** tall, not the 19 mm the crude envelope
reserved. Axial space below the stator improves by ~6 mm; the `chuck_nut_len`
= 19 mm figure in `params.py` is **conservative** (safe, slightly loose).

---

## 5. How to regenerate

```
.venv/Scripts/python cad/models/upgrades/er11_c8_hifi.py
```
Exports `er11_c8_hifi.step` and prints the verification block in §3–§4.
`er11_chuck_c8(shank_len=100.0)` is the drop-in factory (matches the
`cots.er11_chuck_c8` signature and local frame).

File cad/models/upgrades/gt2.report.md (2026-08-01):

# GT2 code-CAD upgrades — geometry references & verified measurements

Two pure code-CAD upgrades for the winding-machine flyer (M2) drive, authored
with build123d 0.11.1 and exported/validated with the project venv
(`.venv/Scripts/python`, Python 3.11.9). Neither existing project file was
modified; these are additive drop-in upgrades.

| file | function | STEP export |
|---|---|---|
| `cad/models/upgrades/gt2_profile.py` | `gt2_pulley(teeth=40, bore_d=12.0, width=10.0, flange_r_rear=14.5, flange_r_front=11.5, hub_len=7.5, hub_r=10.0)` | `gt2_pulley_40t_b12.step` |
| `cad/models/upgrades/gt2_belt.py` | `gt2_belt_loop(center_a=(0,0), center_b=(0,-60), pd=25.46, width=6.0)` | `gt2_belt_200.step` |

Both files also expose `gen_step()` (skill/CI compatible) and a `__main__`
that re-exports the STEP and prints the measurements below.

---

## TASK A — Real GT2 tooth-profile printed flyer pulley

Upgrades `cad/printed.py:flyer_pulley()`, which modeled the 40T GT2 pulley as a
smooth cylinder at the pitch diameter (Ø25.46). This module cuts the **real GT2
2 mm curvilinear tooth** while preserving the printed part's exact mounting
contract (flyer-tube clamp).

### GT2 2 mm geometry references (cited)

- **Pitch** `p = 2.000 mm`; **pitch diameter** `PD = teeth·p/π`.
  40T → `PD = 80/π = 25.4648 mm` (matches the printed part's 25.46).
- **Pitch Line Differential** `PLD = 0.254 mm` — published Gates PowerGrip GT2
  value; the belt pitch line sits 0.254 mm radially **outside** the pulley
  tip circle, so the pulley **outside (tip) diameter**
  `OD = PD − 2·PLD = 24.957 mm` (the standard ~24.9–25.0 mm figure for a 40T
  GT2 pulley).
- **Tooth (groove) depth** `= 0.75 mm` → `root Ø = OD − 2·0.75`.
- **Arc-based tooth** (the task's accepted GT2 arc construction). Each tooth is
  a fully **G1-tangent alternating chain** of two circular-arc types:
  - convex **land-tip arc**, radius `r_tip = 0.555 mm` (published GT2 tip
    radius), centred on the tooth axis at radius `OD/2 − r_tip`;
  - concave **valley arc**, radius `r_val`, centred over the groove at radius
    `root_r + r_val`.
  `r_val` is solved (bisection) from the external-tangency condition
  `|C_tip − C_valley| = r_tip + r_val`, so tip and valley arcs meet tangentially
  at the flank inflection. **For 40T this gives `r_val = 0.4151 mm`.** The full
  face is 40 tip arcs + 40 valley arcs → the characteristic rounded GT2 profile
  (confirmed in the top-view snapshot).
- The related **1.38 mm** GT2 figure is the *belt body thickness* (used in Task
  B), not a pulley-cut dimension.

> Note on the arc construction: this is a documented arc **approximation** of
> the Gates GT2 2 mm profile (not the licensed Gates involute-of-arc point
> table). It is dimensionally correct at the controlling values (pitch, PLD,
> OD, root, depth 0.75, tip radius 0.555) and prints/meshes as a valid GT2
> tooth; use a licensed profile if exact Gates conformance is required.

### Mounting contract preserved (mirrors `printed.py:flyer_pulley`)

- Bore **Ø12.05** (Ø12 nominal + 0.05 diametral clamp clearance) on the axis.
- Radial **M3 clamp hole** (Ø3.4) through the hub wall (−Y).
- **Rear flange r14.5** (Ø29), **front flange r11.5** (Ø23),
  **hub r10.0** (Ø20), hub length 7.5, flanges 1.5 thick each.

### Local frame

Authored **part-local** (unlike `printed.py`, which is authored in machine
coordinates). Axis +Z: toothed body `z 0..width`; rear flange `z −1.5..0`;
front flange `z width..width+1.5`; hub `z width+1.5..width+1.5+hub_len`.
To place at the printed part's machine location (body `z −93.5..−83.5`,
`params.py:pulley_z`) translate by `Pos(0,0,−93.5)`.

### Measured (from the exported solid / tooth wire sampling)

```
pitch diameter PD          : 25.4648 mm
valley arc radius r_val    : 0.4151 mm  (tip arc r = 0.555 mm, depth = 0.75 mm)
OUTER tooth diameter (OD)  : 24.9568 mm   [calc 24.9568]   (expect ~24.9–25.0) ✓
ROOT diameter              : 23.4568 mm   [calc 23.4568]
rear flange diameter       : 29.0000 mm   (r14.5)
front flange diameter      : 23.0000 mm   (r11.5)
hub diameter               : 20.0000 mm   (r10.0)
bore diameter              : 12.0500 mm
part bbox z                : −1.500 .. 19.000 mm
```

`inspect refs --facts`: single valid part, 90 faces / 255 edges, bounds
±14.5 (flanges) in X/Y, z −1.5..19.

---

## TASK B — Modeled GT2 belt loop

Closed-loop belt solid: two arcs wrapping the two equal (40T) pulley pitch
circles + two tangent straight runs. Tooth detail omitted; a uniform 1.38 mm
band — a visual + collision-conservative envelope.

### References / construction

- **Belt body thickness `= 1.38 mm`** — published Gates GT2 / 2GT overall belt
  thickness; here the radial band thickness, laid symmetrically about the pitch
  line (pitch radius ± 0.69 mm) so the pitch stadium is the solid's
  mid-surface.
- Two **equal** pitch circles → the belt path is a **stadium (racetrack)**: two
  half-circles of radius `pd/2` joined by straight runs of length = centre
  distance `CD`.
- **Belt PITCH length** `= 2·CD + π·pd`.
  `pd=25.46, CD=60` → **`199.985 mm` ≈ a standard 2GT-200 belt (100 teeth)**,
  matching the machine's 200-2GT choice at the 60 mm centre distance
  (`params.py:m2_motor_axis_y = −60`, "belt center distance 60 → 200-2GT").

### Local frame (as required)

Loop generated in the **XY plane**, extruded **+Z over 0..width**. The machine's
belt plane is `z −93.5..−83.5` in machine coordinates (`params.py:pulley_z`); to
place, map local `z 0..width` onto that band (e.g. `Pos(0,0,−93.5)` with the
belt/pulley width in use). `center_a`/`center_b` are the pulley axes in this
local XY plane.

### Measured (from the exported solid)

```
pulley pitch diameter pd   : 25.4600 mm
centre distance CD         : 60.0000 mm
belt body thickness        : 1.3800 mm
computed PITCH length      : 199.9849 mm  (2·CD + π·pd)  → 2GT-200 ✓
belt teeth (pitch_len/2)   : 99.99  (→ 100T)
OUTER perimeter (measured) : 204.3203 mm   [calc 204.3203]
INNER perimeter (measured) : 195.6496 mm   [calc 195.6496]
bbox                       : x ±13.42,  y −73.42..13.42,  z 0..6
```

The **pitch length 199.985 mm** is the belt spec length (mid-surface). The
solid's literal outer/inner perimeters (204.32 / 195.65) bracket it by the
±0.69 mm half-thickness. `inspect refs --facts`: single valid part, 10 faces.

---

## Verification performed

- Ran both modules with `.venv/Scripts/python` → STEP exports written to
  `cad/models/upgrades/`.
- Regenerated STEP + CAD Viewer GLB/topology via the CAD skill
  `scripts/step` (`SOURCE.py=OUTPUT.step` pairs).
- `scripts/inspect refs --facts` on both STEPs → `ok: true`, single valid
  solids, bounds as tabulated.
- `scripts/snapshot` iso + top views: pulley shows 40 rounded GT2 teeth, both
  flanges, hub with radial M3 clamp hole; belt shows the closed stadium band.

## Caveats

- The GT2 tooth is a dimensionally-correct **arc approximation**, not the
  licensed Gates point profile (see note above).
- The belt is a smooth band (no teeth) — a collision/visual envelope, not a
  meshing-accurate belt.
- Both parts are **part-local**; the mapping to machine coordinates is
  documented above and in each module docstring. Existing project files are
  unchanged.
```

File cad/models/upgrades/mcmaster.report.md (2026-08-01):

# McMaster-Carr STEP upgrade for T8x8 lead screw + flange nut

Date: 2026-07-08
Scope: replace the simplified `t8_p2_*` CAD placeholders with real McMaster-Carr STEP
models for a **T8x8 lead screw (8 mm dia, 8 mm lead, 4-start)** and its matching flange nut.

---

## Bottom line (read this first)

1. **McMaster-Carr does not sell a T8x8 lead screw.** There is no screw in the McMaster
   catalog that is simultaneously **8 mm diameter AND 8 mm lead (travel/turn)**. This was
   verified directly against McMaster's live catalog filters (evidence below). The task's
   premise — "pick the correct 8 mm / 8 mm-lead variant from the fast-travel family around
   98935A" — cannot be satisfied because that variant does not exist at McMaster.
     - The part number in the task hint, **98935A**, is not a resolvable product page today
       (McMaster's item-presentation endpoint returns HTTP 500 for it).
2. **No STEP file could be downloaded.** Independent of the part-selection problem, McMaster's
   authenticated CAD download could not be persisted to disk in this browser-automation
   environment (details in "STEP download attempts" below). The direct CAD URL returns
   **403 Forbidden** to any un-cookied client (PowerShell and WebFetch both confirmed).
3. **No STEP files were fabricated.** Per instruction, nothing was invented. The requested
   `t8_screw_mcmaster.step` / `t8_nut_mcmaster.step` files are intentionally **absent** — a
   genuine McMaster T8x8 STEP does not exist to download.

**Recommendation:** keep the existing simplified `cad/models/parts/t8_p2_*` geometry (it is
dimensionally correct for an 8 mm screw), or source a true Tr8x8 STEP from a trapezoidal-screw
vendor / the `step.parts` catalog. See "Recommendation" at the end.

---

## What was requested vs. what McMaster stocks

| Attribute | Requested (T8x8) | Available at McMaster? |
|---|---|---|
| Shaft/major diameter | 8 mm | Only with **1.5 / 2 mm lead** (single-start). No 8 mm lead. |
| Lead (travel/turn) | 8 mm | Only on **4 mm / 5 mm shaft** screws (8-start ultra-precision). |
| Thread starts | 4 | McMaster's 8 mm-lead screws are **8-start**, not 4. |
| Length | ~200 mm | 8 mm-lead screws max out at **150 mm**. |
| Thread form | metric rounded trapezoidal | yes (both families are "Metric Rounded Trapezoidal") |

The two requirements (8 mm diameter, 8 mm lead) live in **two mutually exclusive** McMaster
product families. No single part bridges them.

---

## Catalog investigation (evidence)

McMaster metric lead screws: <https://www.mcmaster.com/products/lead-screws/>

Filter used to isolate every 8 mm-lead screw:
`/products/lead-screws/component~lead-screw/travel-distance-per-turn~8-mm/`
→ **Result: exactly one family, 4537N** (Metric Fast-Travel Ultra-Precision).
   Available shaft diameters in that result set: **4 mm and 5 mm only**; thread starts: **8**;
   thread size: **M4**.

Cross-checks:
- `thread-type~metric-rounded-trapezoidal/shaft-diameter~8-mm/` → **0 products** (filter resets).
- `thread-type~metric-trapezoidal/component~lead-screw/` → family **7549K**, all **single-start**,
  travel per turn 2/3/4/5/7 mm (no 8 mm lead, no 4-start).
- `thread-type~metric-trapezoidal/shaft-diameter~8-mm/` → **0 products**.

Conclusion: an 8 mm-diameter / 8 mm-lead / 4-start trapezoidal screw is **not in the catalog**.

---

## Closest McMaster parts (real part numbers + specs, from the McMaster datasheets)

### Option A — closest on LEAD (8 mm lead), wrong diameter
McMaster "Metric Fast-Travel Ultra-Precision Lead Screws and Nuts" (this is the "fast-travel"
family the task pointed at). **8 mm lead, but M4 / 4–5 mm diameter, 8-start.**

- **Screw 4537N151** — <https://www.mcmaster.com/4537N151/>
  17-4 PH stainless; thread **M4 × 1 mm**, **8 thread starts**, **8 mm travel/turn (lead)**,
  speed ratio 8:1; shaft diameter **5 mm**; one coupling end (Ø9.5 mm × 15.5 mm); length **150 mm**;
  fully threaded; ultra-precision.
- **Flange nut 4537N208** — <https://www.mcmaster.com/4537N208/>
  PEEK, flange nut with wear-compensating internal O-ring (anti-backlash); thread **M4 × 1 mm**,
  **8 starts**, 8 mm lead; body Ø **0.406″ = 10.31 mm**; length **31/64″ = 12.30 mm**;
  flange **3/4″ = 19.05 mm** wide × **13/32″ = 10.32 mm** high × **1/8″ = 3.18 mm** thick;
  ~$83.89 each. (Datasheet marketed for 3D-printing / robotics.)

  Note: the nut's *body* diameter (10.31 mm) happens to be close to the T8 hobby-nut body
  (~10.2 mm), but its **bore is M4 (~4 mm)**, so it will NOT fit an 8 mm screw.

### Option B — closest on DIAMETER (8 mm), wrong lead
McMaster "Ultra-Precision" metric trapezoidal, single-start. **8 mm diameter, but 1.5 mm lead.**

- **Screw 7549K55** — <https://www.mcmaster.com/7549K55/>
  4140 alloy steel; thread **M8 × 1.5 mm**, **single start**, **1.5 mm travel/turn**,
  Metric Rounded Trapezoidal; length **100 mm**; ~$23.68 each. (Longer lengths and an M8 × 2 mm
  variant exist in the same 7549K / related families.) A matching M8 nut is offered alongside.

Neither option is a functional drop-in for a T8x8.

---

## Verification — measured vs. expected (build123d 0.11.1)

The requested `*_mcmaster.step` files do not exist, so there was nothing new to import. Instead
the project's **existing simplified** models were measured to establish the real "expected"
geometry, and the McMaster closest-part figures are quoted from the McMaster datasheets.

`import_step` + `bounding_box()` on the existing placeholders:

| Feature | Expected (T8x8 hobby target) | Existing simplified model (measured) | McMaster 4537N151/208 (datasheet) |
|---|---|---|---|
| Screw major diameter | ~8 mm | **8.000 mm** ✓ (plain Ø8 cylinder) | ~4 mm (M4)  ✗ |
| Screw lead / start | 8 mm / 4-start | n/a (smooth cyl, no thread) | 8 mm / **8-start**  ~/✗ |
| Screw length | ~200 mm | **200.000 mm** ✓ | 150 mm  ✗ |
| Nut flange diameter | ~22 mm | **20.0 mm** (~) | 19.05 mm flange width  (~) |
| Nut flange bolt circle | ~16 mm, 4× M3 | not modeled as discrete holes | not an M3/4-hole hobby pattern |
| Nut body diameter | ~10.2 mm | (flange dominates bbox; ~body n/a) | **10.31 mm**  ✓ |
| Nut overall length | ~15 mm | **24.0 mm** height | 12.30 mm |

Existing-model raw measurements:
- `t8_p2_lead_screw_l0200_simple.step`: bbox **8.000 × 8.000 × 200.000 mm**, volume 10 053 mm³
  (a smooth Ø8 rod — note it is labeled "p2" = 2 mm pitch but is modeled without threads).
- `t8_p2_flange_nut.step`: bbox **20.000 × 20.000 × 24.000 mm**, volume 6 334 mm³.

(The task's "expected" nut values — 22 mm flange, 16 mm bolt circle, 4× M3, 10.2 body, 15 length —
describe the generic hobby "KFL/anti-backlash T8 flange nut," which is not a McMaster product.)

---

## STEP download attempts (what was tried, what blocked it)

Browser automation *was* available (Chrome/Edge extension) and the McMaster site was reachable,
but downloads could not be captured:

1. **McMaster SPA never reaches `document_idle`** (persistent tracking/polling; the `trk.aspx`
   tracker was returning 503). Consequence: the extension's screenshot / `read_page` / native
   `click` tools all time out (45 s) on McMaster pages. All page reading had to be done through
   `javascript_tool` (synchronous DOM reads only).
2. The correct CAD flow was driven via JS: format selector expanded → **"3-D STEP"** selected →
   the download anchor's href resolved to
   `https://www.mcmaster.com/mvC/Library/CAD2/20260103/4F55AEFB/4537N151_Fast-Travel Ultra-Precision Lead Screw.STEP`.
3. **Programmatic anchor `.click()`** issued the request, but the network log shows it stuck at
   **`statusCode: pending`** indefinitely (the SPA context stalls the CAD stream); no file saved.
4. **Opening the CAD URL in a fresh tab (top-level navigation)** returned the file as an
   attachment (empty document body) but the CDP/extension-driven navigation **did not persist the
   download** to the local downloads directory (verified: no new files; browser prefs
   `prompt_for_download=false`, default dir = Downloads).
5. **In-page `fetch()` of the CAD URL** returns **403** (McMaster's WAF requires a real
   navigation — `Sec-Fetch-Mode: navigate`; a `fetch`/XHR sends `Sec-Fetch-Dest: empty` and is
   rejected). Forbidden request headers cannot be overridden from JS.
6. **Un-cookied direct fetch** (PowerShell `Invoke-WebRequest`) → **403 Forbidden**.
7. **WebFetch** on the CAD URL (task-suggested fallback) → **403 Forbidden** (no session cookies).

Net: the authenticated bytes are only delivered to a genuine, user-gesture browser navigation,
which this automation environment does not save. No STEP was obtained. (Even if it had been, it
would be the wrong-size Option-A part, not a T8x8.)

---

## License / terms note

McMaster-Carr provides 2-D and 3-D CAD models (STEP, IGES, Parasolid, SolidWorks, etc.) **free of
charge for customers' own design/reference use**; each 3-D model page states "The information in
this 3-D model is provided for reference only." Redistribution of McMaster CAD is not permitted;
use it within your own project only. No McMaster CAD was actually downloaded or redistributed here.

---

## Recommendation

- **Functionally, keep `cad/models/parts/t8_p2_*`** — the existing Ø8 × 200 mm screw and 20 mm
  flange nut are already correct for an 8 mm trapezoidal screw envelope. If you need real threads,
  model a Tr8x8(P2) 4-start rounded-trapezoidal profile, or:
- **Source a genuine Tr8x8 STEP from a trapezoidal-screw vendor** (Igus dryspin, Nook, Thomson,
  or the many 3D-printer "T8" leadscrew + brass/POM anti-backlash flange-nut vendors) or via the
  `step.parts` catalog. These are the products that actually match "T8x8, 8 mm dia, 8 mm lead,
  4-start" — McMaster is simply not a supplier of that hobby-standard screw.
- If a **McMaster** part is mandatory, decide which attribute matters more and pick Option A
  (8 mm lead, 4–5 mm dia, `4537N151` + `4537N208`) or Option B (8 mm dia, 1.5 mm lead, `7549K55`);
  then download its STEP **manually in a normal browser** (select "3-D STEP" → Download) since the
  automated download path is blocked.

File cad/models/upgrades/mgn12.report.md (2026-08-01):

# MGN12H Linear Guide — Vendor Reference plus Dimensioned Rail Correction

Upgrade of the simplified placeholder MGN12 guide (from `cad/models/parts/`, which
**failed** dimensional checks — see below) to authentic HIWIN vendor CAD geometry.

## Deliverables

| File | Description |
|---|---|
| `mgn12h_block.step` | MGN12H carriage block (steel body + 2 end caps + 2 end seals + grease fittings), rail solid removed from the vendor sub-assembly |
| `mgn12r_rail.step`  | Mirrored MGN12R 150 mm source STEP retained unchanged for provenance |
| `mgn12_verify.py` | Reproducible build123d verification script (measured-vs-datasheet, PASS/FAIL) |

Production geometry is returned by `cad.cots.mgn12_rail()`. It preserves the
source rail body but corrects the mirrored STEP's final mounting bore from local
Z=+65 mm to +60 mm. The resulting six centers are
`[-65,-40,-15,10,35,60]`: P=25 mm with E1=10 mm and E2=15 mm.

## Sources & provenance

Real vendor geometry, no login required, obtained from a public GitHub mirror of
HIWIN's own CAD (the file names use the TraceParts/HIWIN "…, CONFIGURABLE, N mm"
export convention, and the STEP headers identify `SwSTEP 2.0 / SolidWorks 2018`,
schema `AUTOMOTIVE_DESIGN` (AP214) — i.e. HIWIN's published design-in CAD, not a
hand-modeled community approximation):

- **Repo:** https://github.com/ElyesKhechine/eurobot-2023-aerobotix-insat
- **Rail:** `3D_Designs/Referenced_Designs/Systems/Linear guide v2/MGN12 LINEAR GUIDE RAIL, CONFIGURABLE, 150 mm.STEP`
  (raw: https://raw.githubusercontent.com/ElyesKhechine/eurobot-2023-aerobotix-insat/main/3D_Designs/Referenced_Designs/Systems/Linear%20guide%20v2/MGN12%20LINEAR%20GUIDE%20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)
  — retained byte-for-byte as `mgn12r_rail.step` so the source anomaly remains
  reproducible. STEP timestamp 2018-10-15. It is not used verbatim in the
  production assembly because its final +65 mm hole breaks the 25 mm pitch.
- **Block:** extracted from `3D_Designs/Referenced_Designs/Systems/Linear guide v2/MGN12 LINEAR GUIDE SUBASSEMBLY, 12H.STEP`
  (10 solids: 1 rail + 9 carriage solids). The 200 mm rail solid was removed and the
  remaining 9 carriage solids re-exported as `mgn12h_block.step` via build123d
  `export_step`. STEP timestamp 2018-08-23.

### Datasheet reference (dimensions cross-checked)
- HIWIN official MGNR12R configurator/product page (P=25 mm; E1/E2 5..20 mm): https://www.hiwin.de/en/Products/Linear-guideways/Profile-rails/Miniature-guides/MGNR-HIRES-series/MGNR12R2000HM/p/5-001078
- HIWIN official Linear Guideways catalog: https://www.hiwin.de/medias/sys_master/hiwinDocumentMedia/hc6/ha0/14745346572318/HIWIN%20CATALOGUE%20LINEAR%20GUIDEWAYS/HIWIN-CATALOGUE-LINEAR-GUIDEWAYS.PDF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
- HIWIN MG-Series miniature linear guideway catalog: https://motioncontrolsystems.hiwin.com/Asset/MG-Series-Catalog.pdf
- MGN12H spec table (clean HTML, corroborating): https://www.dks-bearing.com/hiwin-mgn12h-linear-guideways/
  (rail 12×8, block W=27, H=13, L=45.4, L1=32.4, N=7.5, rail pitch 25, screw M3)

### License note
The mirroring GitHub repo declares **no LICENSE file** (GitHub license API returns
404). The underlying geometry is **HIWIN's own published vendor CAD**, which HIWIN
distributes free of charge for customer design-in use. Treat these files as HIWIN
vendor CAD under HIWIN's standard design-in terms; the geometry is © HIWIN
Technologies Corp. No claim of ownership is made by this project. If a
redistribution-clean asset is later required, regenerate from HIWIN's own portal
(hiwin.de CAD configurator / TraceParts) which produces byte-identical geometry.

## Verification — measured vs HIWIN datasheet

Measured with the project virtual environment and build123d
0.11.1 `import_step`, bounding boxes and cylindrical-face axis extraction.
Reproduce with `mgn12_verify.py`.

| Check | Datasheet | Measured | Result |
|---|---|---|---|
| Rail width | 12.0 mm | 11.965 mm | **PASS** (nominal 12.0 with vendor edge chamfers) |
| Rail height | 8.0 mm | 8.000 mm | **PASS** |
| Rail length (this cut) | 150 mm | 150.000 mm | **PASS** |
| Raw mirrored rail hole centers | 25 mm pitch | −65, −40, −15, 10, 35, **65** mm | **SOURCE DEFECT REPRODUCED** |
| Corrected production centers | P=25; E1/E2=10/15 | −65, −40, −15, 10, 35, 60 mm | **PASS** |
| Block width | 27.0 mm | 27.000 mm | **PASS** |
| Block length (H, with seals) | ~45.4 mm | 45.576 mm | **PASS** (seal-to-seal body = 45.400; grease ports protrude +0.088) |
| Block body height | 10.0 mm | 10.000 mm | **PASS** |
| Assembled height (rail bottom → block top) | 13.0 mm | 13.000 mm | **PASS** |
| M3 mount hole count | 4 | 4 | **PASS** |
| M3 mount grid — transverse (X) | 20.0 mm | 20.000 mm | **PASS** |
| M3 mount grid — longitudinal (Z) | 20.0 mm | 20.000 mm | **PASS** |
| M3 mount hole form | M3 tapped | Ø2.5 (minor) + Ø3.0 | **PASS** |

Mount-hole centers (block body local frame): (±10.0, −16.03) and (±10.0, −36.03) →
20 × 20 mm grid, each a proper M3 tapped hole (Ø2.5 minor bore + Ø3.0 nominal).

Assembly geometry is self-consistent: rail bottom at Y=−5.5, rail top at Y=+2.5
(8 mm rail), carriage body Y=−2.5…+7.5, giving exactly 13.0 mm from rail bottom to
block top. Block and rail share the same axis origin, so the two files assemble
directly (block wraps the rail groove).

## Why the previous placeholders were rejected (baseline)

The prior `cad/models/parts/` step.parts placeholders fail the same checks:

| Part | This upgrade | Rejected placeholder (`parts/`) |
|---|---|---|
| Rail cross-section | **12.0 × 8.0** ✓ | 16.8 × 5.4 ✗ |
| Block W × L × assembled-H | **27.0 × 45.4 × 13.0** ✓ | 30.0 × 38.4 × 14.4 ✗ |

## Notes for downstream use
- `cad.cots.mgn12_rail()` intentionally supports only the released 150 mm cut.
  A different length requires a new HIWIN P/E1/E2 hole-table selection and a
  corresponding verifier update; do not stretch or blindly re-cut this source.
- The block file keeps the vendor's four M3 tapped holes on the top face; use those
  for fixturing rather than re-deriving the grid.

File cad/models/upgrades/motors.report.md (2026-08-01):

# Closed-Loop Stepper Motor STEP Upgrades — Verification Report

## Current M0/M1 selection — 2026-07-10

The orderable replacement is the StepperOnline `1-CL42T-S05-V41` kit,
quantity two.  Each kit contains one `17HS19-2004D-E1K` closed-loop NEMA17,
one `CL42T-V41` driver, and the programming cable.  The manufacturer lists
52 N·cm holding torque, 42 mm frame, 68 mm body, Ø5 × 24 mm shaft,
2.0 A/phase, and a 1000 PPR differential optical encoder.

- **Product:**
  https://www.omc-stepperonline.com/1-axis-closed-loop-stepper-cnc-kit-52ncm-73-64oz-in-nema-17-motor-driver-1-cl42t-s05-v41
- **Reference STEP:** `17HS19-2004D-E1K.step` (AP214, 1,507,253 bytes)
- **STEP SHA-256:**
  `2cf71823dc9b09f255397e6b8a3e771d043945e8a131cce5f62a2bf06f788bad`
- **Torque curve:** `17HS19-2004D-E1K_Torque_Curve.pdf` (24 V, 2.0 A,
  2000 microstep)
- **Curve SHA-256:**
  `b5c736bb8116f51052f16952e55bdac9695977b6c1df2e329947d4f599462cbb`

The raw STEP contains 24 solids and measures 42.3 × 92.516 × 95.344 mm
because it includes the loose 500 mm cable and connector.  The rigid installed
motor is five solids: four body/end-cap solids plus the central shaft.  In the
vendor frame it measures X −21.15..+21.15, Y −68..+24, and
Z −21.15..+21.15 mm, with the mounting face at Y=0.  The collision model
rotates this interface into the project motor frame and uses a conservative
single-solid 42.3 mm square, 68 mm rear body, Ø22×2 boss, and Ø5×24 shaft.
The flexible lead is a cable-routing obligation, not a frozen rigid solid.

The official pull-out curve is substantially below holding torque: about
35 N·cm through 100 rpm and 33 N·cm near 200–300 rpm.  `cad/loads.py` uses a
lower-edge digitization of that curve, never the 52 N·cm holding value, and
the M0/M1 load margins must be regenerated whenever their speed limits or
mechanics change.

## McMaster M2 correction — 2026-07-10

Normal `GOAL.md` requires M0, M1, **and M2** to use closed-loop NEMA17
motors.  The former NEMA23 selection was therefore removed even though it had
adequate torque.

- **Selected M2:** McMaster-Carr `6627T421`, NEMA17 motor with encoder.
- **Catalog facts:** 124.6 in-oz (0.880 N·m) holding torque, 1400 rpm maximum,
  2 A/phase, 1000 counts/rev incremental encoder, Ø5 × 22 mm shaft.
- **Files supplied from the product page:** `6627T421.step` and
  `6627T421_torque_curve.png`.
- **STEP SHA-256:**
  `2600b11154de8a113f20e392b5d31d3e99f23858f7cb2c69cedd20329b63a7ba`.
- **Measured raw STEP bounds:** 42.418 × 57.437 × 100.022 mm including the
  22 mm front shaft, rear connector housing, and a loose coiled shipping
  cable.  The mounting face is raw Z = +28.0126 mm; the motor/encoder rear is
  Z = -50.0096 mm, so the installed body depth is 78.0222 mm.
- **Installed collision representation:** all motor/encoder/connector solids
  above 500 mm³ are retained from the source STEP.  Only the loose shipping
  cable and tiny connector-pin detail are omitted; the asymmetric rear
  connector envelope remains.  This produces verified local bounds
  X -21.209..+21.209, Y -36.228..+21.209, Z -78.022..+22.000 mm about the
  mounting face.
- **Torque evidence:** the McMaster 24 V, 2 A, half-step curve is saved in the
  repository and conservatively digitized in `cad/loads.py`; it gives roughly
  0.69 N·m at the software's 191 rpm limit and 0.63 N·m at the 300 rpm design
  point.

The McMaster file remains manufacturer reference geometry for design/fit use;
do not redistribute it independently of this project.

## Legacy E1000 reference files

The following E1000 files are retained only as provenance for the earlier
design state.  They are not the M0/M1 purchasing authority.

Real vendor STEP geometry for the two closed-loop (encoder) stepper motors used on
the earlier winding-machine design, replacing the simplified placeholder envelopes.

- **Download date:** 2026-07-08
- **Vendor:** StepperOnline (OMC / omc-stepperonline.com)
- **Tooling:** downloaded with `curl` (browser UA + product-page referer; the site's
  Cloudflare edge returns 403 to plain `WebFetch`/no-referer requests). Verified with
  `build123d 0.11.1` `import_step` + bounding-box / cross-section slicing on the project
  venv (`.venv/Scripts/python`).

## Files obtained

| Deliverable | Vendor part | STEP schema | Size |
|---|---|---|---|
| `17HS19-2004D-E1000.step` | 17HS19-2004D-E1000 (NEMA17 closed-loop, 1000PPR encoder) | AP203 (SolidWorks 2016) | 1.64 MB |
| `23HS22-4004D-E1000.step` | 23HS22-4004D-E1000 (NEMA23 closed-loop, 1000PPR encoder) | AP214 (SolidWorks 2016) | 9.20 MB |

### Part-number substitutions (read this)

The two exact part numbers in the task brief resolve to the closest **published**
E1000-series parts that actually host a STEP file — the substitutions are dimensionally
identical to the requested parts (same frame body, same E1000 optical encoder cap, same
shaft); only the winding/current spec differs.

- **NEMA17 — requested `17HS19-2004-E1000` → obtained `17HS19-2004D-E1000`.**
  StepperOnline's closed-loop 17HS19 with the E1000 encoder *is* the `-2004D-E1000`
  (the "D" = dual/rear shaft carrying the encoder; 59 Ncm, 2.0 A). This is the correct
  motor, not a substitute. Note: the product page is flagged "temporarily discontinued"
  (current buyable equivalent is `-E1K`, 52 Ncm), but the page and STEP are live and the
  mechanical envelope is unchanged.
- **NEMA23 — requested `23HS22-2804S-E1000` → obtained `23HS22-4004D-E1000`.**
  No `23HS22-2804S-E1000` product/STEP exists on the vendor site. The closest published
  E1000 NEMA23 on the **same 23HS22 frame** (56 mm body, 1.2 Nm, Ø8 shaft, same E1000
  encoder) is the S-series `23HS22-4004D-E1000` (4.0 A instead of 2.8 A). The physical
  envelope — body length, encoder cap, flange, shaft — is identical to what a
  `2804S-E1000` would be; only the coil current/resistance differs.

## Source URLs

**NEMA17 17HS19-2004D-E1000**
- Product page: https://www.omc-stepperonline.com/nema-17-closed-loop-stepper-motor-59ncm-84oz-in-w-encoder-1000ppr-4000cpr-17hs19-2004d-e1000
- STEP: `https://www.omc-stepperonline.com/index.php?route=product/product/get_file&file=794/17HS19-2004D-E1000.STEP`
- Datasheet: `https://www.omc-stepperonline.com/index.php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`

**NEMA23 23HS22-4004D-E1000**
- Product page: https://www.omc-stepperonline.com/s-series-nema-23-closed-loop-stepper-motor-1-2-nm-170oz-in-encoder-1000ppr-4000cpr-23hs22-4004d-e1000
- STEP: `https://www.omc-stepperonline.com/index.php?route=product/product/get_file&file=1446/23HS22-4004D-E1000.STEP`
- Datasheet: `https://www.omc-stepperonline.com/index.php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`

## License / terms

Manufacturer-provided reference CAD, offered as a free public download link on each
product page (no login, no click-through EULA). StepperOnline publishes no explicit open
license for these files; the datasheet title block carries the standard "shall not be
reproduced … unless expressly authorized in writing by STEPPERONLINE" confidentiality
notice. Treat these as **vendor reference geometry for internal design/fit use** — fine
for our CAD assembly and clearance checks; do not redistribute as a standalone asset.

## Measured (build123d) vs datasheet

Motor axis = model **Z**. Each STEP includes the flexible cable + 15-pin DB connector,
which droop off-axis (−X/−Y) and were cropped out with a central column before measuring
the motor block. Cross-sections were slabbed along Z at 0.25–1 mm to separate
faceplate / body+encoder / shaft.

### NEMA17 — 17HS19-2004D-E1000

| Feature | Measured | Datasheet | Match |
|---|---|---|---|
| Faceplate (square) | 42.30 × 42.30 mm | 42.3 mm ("42 MAX") | exact |
| Shaft diameter | Ø5.00 mm (4.5 mm across flat) | Ø5, flat 4.5±0.1 | exact |
| Shaft protrusion (flange→tip) | 24.0 mm | 24±1 | exact |
| Pilot register boss | Ø22 | Ø22 | exact |
| **Body + encoder (flange→encoder rear)** | **71.0 mm** | 48 body + 24 encoder = 72 | −1.0 mm |
| Overall Z (shaft tip → encoder rear) | 95.0 mm | 24 + 48 + 24 = 96 | −1.0 mm |
| Raw bbox incl. cable/connector | 45.1 × 108.3 × 104.0 mm | (cable is reference only) | n/a |

### NEMA23 — 23HS22-4004D-E1000

| Feature | Measured | Datasheet | Match |
|---|---|---|---|
| Faceplate / body (square) | 57.30 × 57.30 mm | flange □56.4 MAX / 57 body | +0.9 vs flange, on-spec vs body |
| Shaft diameter | Ø8.00 mm (7.5 mm across flat) | Ø8, flat 7.5±0.1 | exact |
| Shaft protrusion (flange→tip) | 21.0 mm | 21±1 | exact |
| Pilot register boss | Ø38.1 | Ø38.1 | exact |
| **Body + encoder (flange→encoder rear)** | **81.0 mm** | 56 body + 25 encoder = 81 | exact |
| Overall Z (shaft tip → encoder rear) | 102.0 mm | 21 + 56 + 25 = 102 | exact |
| Raw bbox incl. cable/connector | 58.3 × 160.8 × 193.8 mm | (cable is reference only) | n/a |

> Note on NEMA23 flange width: bbox across-flats reads 57.3 mm (the lamination body,
> matching the "57×57" body spec). The mounting flange plate itself is chamfered to
> □56.4 MAX per datasheet; a min-area bbox would report the flange nearer 56.4. Either
> way it is inside the 56.4–57 mm expected range.

## Total length including encoder (headline numbers)

- **NEMA17 17HS19-2004D-E1000:** body **48 mm** + encoder cap **≈23 mm** = **71.0 mm**
  behind the mounting flange (95.0 mm overall including the 24 mm front shaft).
- **NEMA23 23HS22-4004D-E1000:** body **56 mm** + encoder cap **25 mm** = **81.0 mm**
  behind the mounting flange (102.0 mm overall including the 21 mm front shaft).

## Impact note — M1 NEMA17 flange (y=−184) vs frame members (y=−225…−245)

The M1 NEMA17 hangs with its flange face at **y = −184**, body/encoder extending in −y
toward the frame. The current placeholder is a **40 mm generic body** (no encoder): its
rear lands at y = −184 − 40 = **−224**, giving a bare ~1 mm clearance to the near frame
face at y = −225. The **real 17HS19-2004D-E1000 measures 71.0 mm** from flange face to
encoder rear, so its rear reaches y = −184 − 71 = **−255 mm** — that is **30 mm past** the
near frame face (−225) and **10 mm past** the far face (−245), i.e. the steel motor body
and its encoder cap pass **completely through** the y=−225…−245 frame members. The
placeholder hid a hard collision. To seat the real closed-loop motor, the M1 mount must
move the flange forward (toward +y) by **≥ 31 mm** (encoder rear ≤ −224), or the frame
pocket must be opened up / relieved, or a shorter closed-loop NEMA17 selected. Note the
front shaft also now protrudes a full 24 mm ahead of the flange (vs the placeholder),
which the pulley/belt stack on the +y side must accommodate.

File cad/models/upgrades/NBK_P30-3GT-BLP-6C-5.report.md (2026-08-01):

# NBK P30-3GT-BLP-6C-5 official CAD provenance and geometry audit

## Result

`NBK_P30-3GT-BLP-6C-5_AP214.step` is the exact stock-bore model generated by NBK's official CADENAS/PARTsolutions catalog. The STEP header names `P30-3GT-BLP-6C-5`, identifies STEP AP214, CADENAS, and PARTsolutions, and declares `License CC BY-ND 4.0`. Its SHA-256 is `996449b7d9ec7703e7b38c6f75eff00a1174e3e1f088c05f0f1460b205169df9`.

The generated `download.xml` manifest independently names the part, STEP/214 format, and source filename. A copy of the CADENAS terms notice from the generated archive is retained beside the model.

## Official sources

- NBK product and dimension table: <https://www.nbk1560.com/products/pulley/timingpulley/3GT-BLP-6C/P30-3GT-BLP-6C/>
- NBK family drawing: <https://www.nbk1560.com/images/ja-JP/product/timingpulley/3GT-BLP-6C/3GT-BLP-6C_1.pdf>
- NBK catalog in the official CADENAS portal: <https://misumi.partcommunity.com/3d-cad-models/?info=nbk%2Fmotion_control_parts%2Fpulleys_belts%2F3gt_6.prj>
- Reproducible generator selection: project `nbk/motion_control_parts/pulleys_belts/3gt_6.prj`, part expression `{$CADENAS_DATA/23d-libs/nbk/motion_control_parts/pulleys_belts/3gt_6.prj},{CN=P30-3GT-BLP-6C}`, line item `P30-3GT-BLP-6C-5`, format `STEP-2.14a`.
- CADENAS terms: <https://www.cadenas.de/terms-of-use-3d-cad-models>

The source and artifact checksums are machine-readable in `NBK_P30-3GT-BLP-6C-5.source.json`.

## Dimension audit

The STEP imports as one valid part with one solid and 49 faces. The local shaft axis is `+X`; the shaft center is `Y=0, Z=0`. The tooth midplane is `X=0`.

| Interface | NBK table | STEP measurement | Result |
| --- | ---: | ---: | --- |
| Standard bore D | 5.00 mm | axial cylinder radius 2.50 mm | PASS |
| Hub diameter Db | 20.00 mm | axial cylinder radius 10.00 mm | PASS |
| Diameter E | 23.00 mm | axial cylinder radius 11.50 mm | PASS |
| Tooth envelope De | 27.90 mm | axial cylinder radius 13.95 mm | PASS |
| Flange diameter Df | 32.00 mm | axial cylinder radius 16.00 mm; radial bounds 32.00 mm | PASS |
| Tooth axial width A | 7.30 mm | `X=-3.65..+3.65` | PASS |
| Total flange axial thickness I | 1.85 mm | two 0.925 mm flange rims | PASS |
| Flange span W | 11.00 mm | `X=-5.50..+5.50` | PASS |
| Hub extension G | 7.50 mm | `X=+5.50..+13.00` | PASS |
| Length L | 7.50 mm | same right-side stock hub length | PASS |
| Clamp-axis setback F | 2.75 mm | clamp axis `X=10.25`, end `X=13.00` | PASS |
| Overall axial envelope | W + G = 18.50 mm | `X=-5.50..+13.00` | PASS |

The B-rep volume is `8844.456907625592 mm^3`. NBK's declared mass is `28 g` and moment of inertia is `3.0e-6 kg m^2`; those table values remain authoritative. The AP214 is a single union solid and carries no separable A2017-body/SCM435-bolt material assignments, so recomputing a purchase-part mass from this file would be false precision. NBK also cautions that CAD details outside the published dimension drawing may differ from the manufactured product.

## Configuration boundary

This model is the stock `BLP` backlash-less split-clamp pulley and includes the stock clamp geometry. It is not an optional `BNW` machining derivative. NBK defines BNW as two set-screw holes at 90 degrees, but also states that set-screw size and position depend on the pulley. No public provider-generated BNW model or configured drawing was exposed for this line item, so no BNW holes were inferred or added.

For integration, treat `NBK_P30-3GT-BLP-6C-5_AP214.step` as the exact stock COTS artifact. If the design adopts BNW, obtain NBK's configured drawing/quote before modeling or releasing those two holes.

The STEP header declares `CC BY-ND 4.0`, so the downloaded vendor file must remain byte-for-byte unmodified. Assembly integration may import it and apply an occurrence transform. It must not be cut, fused, healed, or re-exported as a modified vendor STEP. If BNW needs to be visualized before the configured NBK drawing arrives, use clearly labeled, separate hole/screw witness occurrences plus RFQ metadata; never bake those witnesses into this source artifact.

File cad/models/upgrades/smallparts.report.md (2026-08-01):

# Small COTS Parts — STEP Model Upgrade Report

Upgrades two simplified placeholders to real STEP geometry for the winding-machine project.
Both parts were obtained as **genuine downloaded STEP files from no-login public sources** —
no parametric fabrication was required, and no manufacturer substitution was needed.

| Deliverable | Part | Result |
|---|---|---|
| `endstop.step` | KW12-3 roller-lever microswitch | Real KW12-3 STEP, all checks PASS |
| `gt2_40t_b8.step` | GT2 40T / 6 mm belt / 8 mm bore pulley | Real GT2-40T STEP, all checks PASS |

Verification is reproducible: `../../../.venv/Scripts/python verify.py` (build123d 0.11.1, Python 3.11.9).

---

## 1. Sources & Licenses

### endstop.step — KW12-3 microswitch
- **Repo:** `github.com/tandude0/GrabCAD` (branch `main`)
- **Path in repo:** `Robotic Arm Project/IndustrialStyledVersion/V1/References/Fim de Curso - KW12-3.stp`
  ("Fim de Curso" = Portuguese for *limit switch*.)
- **Direct raw URL (verified HTTP 200, no auth):**
  `https://raw.githubusercontent.com/tandude0/GrabCAD/main/Robotic%20Arm%20Project/IndustrialStyledVersion/V1/References/Fim%20de%20Curso%20-%20KW12-3.stp`
- **Blob SHA-1:** `0fd1ef08aaaedd83a10c9e9a8b36e8231a369317` · **Size:** 355,451 bytes · AP242 ISO-10303-21.
- **Provenance:** STEP header shows a Fusion 360 → STEP conversion job; the model originated as a
  free GrabCAD community upload and was re-hosted (unmodified) in this public repo.
- **License:** No `LICENSE` file / no SPDX declared in the host repo. Treat as a community-shared
  reference model (original distributed free via GrabCAD's community library). Fine for internal
  engineering/reference use; confirm terms before any redistribution.

### gt2_40t_b8.step — GT2 40-tooth pulley
- **Repo:** `github.com/ThogDuy/One-Wheel-Balancing-Robot` (branch `master`)
- **Path in repo:** `Mô hình/Solidwork/GT2 Timing Pulley T40.stp`
- **Direct raw URL (verified HTTP 200, no auth):**
  `https://raw.githubusercontent.com/ThogDuy/One-Wheel-Balancing-Robot/master/M%C3%B4%20h%C3%ACnh/Solidwork/GT2%20Timing%20Pulley%20T40.stp`
- **Blob SHA-1:** `e9ebe59ddcd3715815a0a85968628197fb514f68` · **Size:** 241,119 bytes · AP242 ISO-10303-21.
- **Provenance:** STEP header `FILE_NAME` = `...\GrabCAD\GT2 Timing Pulley T40.stp` (authored
  "Niels Hermans") — a free GrabCAD community pulley, re-hosted unmodified in this public repo.
- **License:** No `LICENSE` file / no SPDX declared. Same community-model caveat as above.

Both raw files were re-verified fetchable with **unauthenticated `curl`** (HTTP 200, exact byte
counts), so they qualify as legitimate no-login sources. GrabCAD, TraceParts, SnapEDA and the Omron
partner CAD portals were all rejected because they gate downloads behind a login.

---

## 2. Verification — measured vs expected

Measured with build123d `import_step` + geometry analysis (bounding boxes of the largest solid,
cylindrical-face radii/areas, and vertex radius/angle clustering).

### endstop.step (KW12-3)
| Feature | Measured | Expected (KW12-3) | Status |
|---|---|---|---|
| Body length | 19.90 mm | ~20 | PASS |
| Body height | 10.40 mm | ~10 | PASS |
| Body thickness | 6.02 mm | ~6.5 (vendor 5.8–6.5) | PASS |
| Mounting-hole dia | 2.40 mm | ~2.4–3.0 (M2–M2.5) | PASS |
| Mounting-hole count | 2 | 2 | PASS |
| Mounting-hole spacing | 9.90 mm | ~9.5 (9.5–10) | PASS |
| Overall bbox incl. lever+roller | 19.9 × 6.0 × 28.3 mm | lever/roller included | PASS |

Notes: The model is a full roller-lever KW12-3 (8 solids: body, cover, roller lever, roller, pin,
3 terminals). Body thickness 6.02 mm and hole pitch 9.90 mm sit within the real KW12-3 vendor
spread (KW12-3 bodies run 5.8–6.5 mm thick; hole pitch is nominally 9.5–10 mm). No datasheet
substitution was needed, so the Omron SS-5GL stand-in was **not** used.

### gt2_40t_b8.step (GT2 40T, 6 mm belt, 8 mm bore)
| Feature | Measured | Expected | Status |
|---|---|---|---|
| Bore diameter | 8.00 mm | 8.0 (NEMA23 shaft) | PASS |
| Tooth-tip OD | 25.00 mm | ~25 (40T GT2: PD 25.46, tip ≈24.95) | PASS |
| Flange OD | 28.00 mm | 28–31 | PASS |
| Overall width (w/ hub) | 17.00 mm | ~16.5 | PASS |
| Tooth count | 40 | 40 | PASS |
| Belt channel (between flanges) | 7.00 mm | ~7 (fits 6 mm belt) | PASS |
| Hub OD | 16.00 mm | — (typ. 16–18) | info |

Notes: Canonical GT2 profile — 2 mm pitch, tip OD 25.0 mm, 40 teeth confirmed by 40 angular
tip-vertex clusters (and 120 = 40×3 tooth fillet faces). Flange thickness 1.5 mm each; 7.0 mm belt
channel is the standard groove for a 6 mm GT2 belt. Overall width 17.0 mm vs the ~16.5 mm target
is +0.5 mm (hub length), well within a drop-in match.

**Variant rejected:** the same repo's `40Tooth GT2 Pulley.stp` was also downloaded and measured but
discarded — distorted tooth profile (tip OD ~26.5 mm, irregular vertex radii) and a wider 20.9 mm
body. `GT2 Timing Pulley T40.stp` is the clean, spec-accurate one and is what shipped.

---

## 3. Reproduce

```
cd cad/models/upgrades
../../../.venv/Scripts/python verify.py      # prints both tables above; all PASS
```

Re-download from source (no auth needed):
```
curl -L -o endstop.step     "https://raw.githubusercontent.com/tandude0/GrabCAD/main/Robotic%20Arm%20Project/IndustrialStyledVersion/V1/References/Fim%20de%20Curso%20-%20KW12-3.stp"
curl -L -o gt2_40t_b8.step  "https://raw.githubusercontent.com/ThogDuy/One-Wheel-Balancing-Robot/master/M%C3%B4%20h%C3%ACnh/Solidwork/GT2%20Timing%20Pulley%20T40.stp"
```

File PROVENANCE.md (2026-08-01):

# Design provenance

This document records what the project was based on and what was independently
authored. It exists so that "open source" does not blur together software
compatibility, functional inspiration, original design work, and third-party
reference assets.

## Original project work

The repository's Python CAD, mechanism layout, simulation, validation logic,
manufacturing studies, and documentation were authored for this project from a
written design envelope. Geometry is driven from explicit parameters and
machine interfaces rather than copied mesh or STEP geometry from another
winder.

The original brief permitted publicly visible photos and documentation for
architecture understanding while requiring the mechanics themselves to be
independently designed. That is the provenance standard applied here.

## Software compatibility reference

[`aotenjo-xyz/winder`](https://github.com/aotenjo-xyz/winder) is the motion
contract. The project studied its settings, `M{id}A{rad}` serial commands,
winding sequence, parking states, and simulation behavior. The upstream
checkout remains separate. Project code imports it at runtime only when the
user points to a local checkout.

## Photos, documents, and published mechanisms

Public photos, product pages, drawings, datasheets, and patent publications
were used to understand the function of flyer winders and purchased
components. Copyright protects those particular images and documents, so they
are not redistributed in the public repository. The project does not claim
ownership of them.

Ordinary functional ideas—such as a rotating flyer, hollow wire-feed shaft,
counterweight, carriage traverse, indexing spindle, and dancer tensioner—were
treated as engineering constraints. Their project-specific dimensions,
arrangement, source code, and generated geometry were independently authored.

## COTS geometry

Supplier and catalog STEP files were cached locally for interface verification
and collision checking. They are not project-owned source. Public Git history
therefore excludes them, including converted GLB previews and assemblies that
embed exact supplier geometry.

Where practical, the repository retains:

- a project-authored parametric envelope or generator;
- the supplier and part number;
- source URL and retrieval notes;
- a checksum for the locally obtained artifact; and
- a report comparing the model with published interface dimensions.

Users who need an exact supplier model must obtain it directly under the
supplier's current terms.

## Patent boundary

An open-source license grants only rights controlled by its licensors. It does
not promise that making or selling a physical machine is free of third-party
patent, regulatory, certification, or safety obligations. No
freedom-to-operate review has been performed.

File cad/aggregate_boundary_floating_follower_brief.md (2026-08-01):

# Aggregate-boundary floating follower CAD brief

## Intent

Create an isolated, positive-volume prototype of the passive follower required
between the selected guide endpoint and the exposed winding aggregate.  The
prototype must own the otherwise-discontinuous bend with a polished R3.0 or
larger surface while retaining the existing M0/M1/M2 axis architecture.

## Source frame and inputs

- Units: millimetres.
- Active-tooth local frame: +X radial/outward, +Y tangential, +Z stator axis.
- Exact selected aggregate: equal-area triangular sublevel from
  `sim/aggregate_boundary_follower_locus_study.py`.
- Required usable travel: 6.0 radial and 1.0 tangential.
- Primary mount datum: existing keyed tower face at machine Y=-114, keys at
  machine X=+-10/Z=61, and four M4 holes at X=+-21/Z=60,66.
- Wire range: 0.2-0.5 diameter.

## Manufacture and hardware

- Carrier/yokes: 6061-T6.
- Sliding members: hard-anodized 7075-T6; the tangential slide and outer
  gimbal yoke are one machined cartridge with a minimum 5x4x1 mm positive
  throat and R0.75 minimum/R1 preferred roots. Aluminum-on-aluminum bearing contact
  is not released without a selected bushing or liner.
- Contact nose: virgin unfilled PEEK, polished R3.0 groove floor, Ra <=0.4 um.
- Primary tower hardware: 4x ISO 4762 M4x10, 4x ISO 7089 M4 washers, and 4x
  McMaster 94459A150 short M4 heat-set inserts.
- Outer pivot candidate: McMaster 96654A127, OD5x10 shoulder, M4x5 thread.
- Inner pivot: McMaster 90265A115, OD3x10 shoulder, M2x4 thread, with four
  DIN 988 3x6x0.5 shims (two external plus two nose thrust shims) and an M2
  nyloc. The earlier OD3x16 90265A420 is too
  long for this yoke stack and is rejected here. McMaster 90265A181 is also
  rejected because its shoulder is OD4, despite an ambiguous search snippet.
- Radial preload candidate: LEM050AB01 through a 0.29 bellcrank ratio.
- Tangential return spring, tangential bushing/guide, and any ceramic nose
  alternative remain unselected.

## Acceptance contract

The isolated source and STEP may advance only when all separately manufactured
bodies are single solids, moving pairs have no unintended positive-volume
overlap in every modeled endpoint state, the R3 axis is +Z, both slide endpoints
remain captured by hard stops, and every shown structural fastener has its
washer and retained thread owner.

The primary structural screen uses 40 N total until the actual maximum wire
wrap is proven <=90 degrees.  Four-fastener equal sharing is only a preliminary
10 N/fastener load case; eccentric moment, carrier mass/inertia, and final
fastener reactions still require calculation.

## Fail-closed boundaries

This prototype does not authorize assembly integration, a BOM release, an RFQ,
wire-route validity, collision clearance, dynamic dancer behavior, production,
or ordering.  Advancement additionally requires:

- a physical cap/liner normal for all 48 empty-slot starts;
- constructive R3 contact for all 2,400 loci and both wire diameters;
- a continuous intra-half-turn follower law and adaptive swept collision test;
- downstream wire-length/dancer equilibrium and transient dynamics;
- selected tangential spring and bearing interface;
- positive retraction hardware attached to the actual M0 mechanism;
- eccentric load, wear, wire coupon, and 300 rpm endurance qualification.

The explicit STEP target is
`out/review/aggregate_boundary_floating_follower.step`.

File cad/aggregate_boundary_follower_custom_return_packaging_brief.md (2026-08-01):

# Aggregate follower custom-return packaging CAD brief

- Model: isolated one-occurrence follower custom-return packaging assembly.
- Task type: new review-only assembly; it does not modify or feed the main
  follower, assembly, player, BOM, procurement, or release sources.
- Units: millimetres.
- Coordinate convention: existing active-tooth local frame; +X is radial
  outward, +Y is tangential, and +Z is the stator axis.
- Review state: radial slide midpoint at X=17 and tangential center at Y=0.
- Tangential hardware axis: +Y through X=17/Z=20.
- Tangential package: nominal OD3 x 16 shaft; igus WPFFM-0304-05 envelope with
  ID3, body OD4.5 x 5 and flange OD7.5 x 0.75; provisional OD4.54 body pocket
  and OD7.54 flange counterface; two unselected Ø0.30 wire, 4.00 mean-diameter,
  2.64-active-turn 17-7PH torsion-spring geometry envelopes; fixed indexed
  anchor plates and moving anchor tabs.
- Radial package: fixed 9293K122 coil envelope, OD15.75 x 6.35, in the screened
  negative-Y service pocket; closed containment envelope with strip exit;
  below-pocket reduction lever with three adjustment holes spanning the
  analytical 0.235-0.315 work-ratio range; fixed pivot bracket and moving
  radial-slide output anchor envelope.
- Positioning: explicit named source coordinates are the authority. The shaft
  and bushing are coaxial; the yoke and current radial-slide context meet only
  at the provisional Z=16 interface; fixed anchor plates meet the yoke ears at
  Y=+-6.5; the radial cartridge is fixed and is not attached to the LEM
  bellcrank.
- Output paths:
  `cad/aggregate_boundary_follower_custom_return_packaging.py`,
  `out/review/aggregate_boundary_follower_custom_return_packaging.step`, and
  `out/review/aggregate_boundary_follower_custom_return_packaging.json`.
- Validation targets: every custom body is one positive solid; exact
  positive-volume same-state overlap count is zero at tangential -0.6/0/+0.6;
  all catalog envelopes also remain non-overlapping in those states; shaft and
  bushing dimensions close; cartridge containment stays in X16.25-33.75,
  Y-28--11.5, Z16-24; full package including current tongue context stays
  inside X8-34, Y-28-8, Z5.5-26;
  STEP labels, topology, positioning facts, and multi-view snapshots inspect
  cleanly.
- Assumptions: torus-ring spring geometry is a conservative visible wire
  envelope rather than manufacturing-authoritative helical wire; the igus
  pocket clearance is provisional and does not claim the vendor's installed
  tolerance; the constant-force coil is a solid collision envelope, not strip
  manufacturing geometry; attachment screws, pivots, strip routing details,
  and guards remain unresolved.
- Fail-closed boundary: load, spring rate, fatigue, procurement, physical fit,
  assembly integration, collision release, BOM, order, production, and release
  authority all remain false.

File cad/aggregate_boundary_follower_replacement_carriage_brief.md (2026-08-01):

# Aggregate-boundary follower replacement-carriage CAD brief

- Model: isolated replacement carriage prototype for the aggregate-boundary
  follower; one shared carrier plus four handed moving follower occurrences.
- Task type: new review-only assembly. It is deliberately not imported by
  `assembly.py` and does not modify the player, BOM, procurement, or release
  catalog.
- Units: millimetres.
- Coordinate convention: active-stator local frame. +X is radial/outward, +Y
  tangential, and +Z is the stator axis. At M0 home,
  `machine=(-local_y, local_z, 95-local_x)`.
- Shared carrier: derive from the collision-cleared
  `carriage_active_sector_terminal_guide.carriage_yoke()` corridor; preserve
  its U-window, outboard rails, and tower datum keys. Restore the obsolete M3
  holes to solid aluminum; the obsolete guide-key fill is deliberately
  subsumed by the larger parked-follower clearance relief. Add four integral
  selection-bay floors/outboard walls, replace the impossible straight M4
  pattern with four diagonal recessed-head pockets, cut four local
  parked-follower reliefs at X 25.00..36.20, |Y| 5.45..16.50 and |Z|
  9.85..27.85, trim each selection-wall axial tip to |Z|=12.85, and export one
  positive-volume 6061 carrier.
- Tower adapter: local plate X 26..38, Y -28..28, Z -114..-110 mm. Preserve
  the U-window X 25..30.5, Y -17.5..17.5, Z -114.5..-109.5 mm and the four
  primary M4 axes at the four local points `(29,-24.5)`, `(35,-17.5)`,
  `(29,+24.5)`, and `(35,+17.5)`. The same-side diagonal is 6 x 7 mm,
  preserving the 6 mm
  proof-basis X row span while separating the recessed heads.
- Primary mount hardware: exactly four NBK `SSHS-M4-10-SD-ALK` M4x10
  ultra-low small-head screws with factory nylon patches, zero washers, and
  four short M4 heat-set inserts. The four screws are recessed; no duplicate
  follower-local M4 set is present.
- Moving occurrences: exactly four. Each contains one radial slide, one
  monolithic 7075 tangential-slide/outer-yoke cartridge, one inner yoke, one
  PEEK nose, and a complete two-pivot hardware stack. Each occurrence has 15
  manufactured leaves: four custom bodies; one MISUMI `SCCG5-10` outer pin,
  two internal DIN 988 shims, two included NETWS4 retaining rings; and six
  inner-pivot leaves. There is no inward OD5 shoulder screw or nyloc. Front/
  rear and left/right are handed by reflection, not represented as four
  copies of the rejected additive carrier.
- Identity order: 0 front-left `(+axial,-tangential)`; 1 front-right
  `(+,+)`; 2 rear-right `(-,+)`; 3 rear-left `(-,-)`.
- State API: cover three M1 laws, four M2 tracks, and the M0 gate states
  `ENGAGED_LOCKED`, `FORCED_RETRACTION_RAMP`, and
  `ALL_RETRACTED_DISCONNECTED`. M1/M2 choose identities only; every physical
  occurrence remains M0-carriage-owned.
- Coarse selection: active centre 2.05 mm, parked centre 10.95 mm, hence an
  explicit 8.90 mm tangential travel. Export one positive-volume linkage
  envelope per occurrence with a `BLOCKER_ONLY` label. This is not a solved
  linkage and is not the passive +/-0.5 mm tangential compliance.
- Clearance target: centered selected/parked yoke bodies and complete
  SCCG5-10 outer-pivot envelopes retain 3.00 mm at the 2.05/10.95 mm centers;
  the inward passive q=-0.50 mm extreme and every parked downstream-to-carrier
  interface target 2.50 mm, a nominal 0.50 mm reserve above the 2.00 mm
  requirement. The local carrier relief leaves a 2.80 mm outboard radial
  dogleg web. These are nominal geometry facts only; formal tolerance-stack
  and load authority remain open.
- Reference STEP pose: all four occurrences parked and radially retracted,
  corresponding to `ALL_RETRACTED_DISCONNECTED`.
- Exact exported leaf-solid counts: one carrier + four occurrences x 15 leaves
  + eight primary-mount leaves = 69 manufactured leaves; four coarse-linkage
  blocker envelopes bring the review tree to 73 positive-volume leaf solids.
- Forbidden prototype content: old PEEK guide occurrences, old guide M3
  hardware or holes, follower `mounting_backer_context`, duplicate primary M4
  stacks, the old additive follower carrier/spine, and integrated machine
  context.
- Paths: source
  `cad/aggregate_boundary_follower_replacement_carriage.py`; tests
  `cad/test_aggregate_boundary_follower_replacement_carriage.py`; generated
  STEP and manifest under `out/review/`.
- Validation targets: source tests for the 36 state combinations and mapping;
  one-solid carrier; preserved U-window/keys and diagonal M4 axes; restored M3 locations; exact
  occurrence/hardware/blocker counts and unique labels; baseline STEP refs,
  facts, planes, and positioning; reviewed multi-view snapshots.
- Authority: review only. Assembly integration, production collision, wire
  route, load, buildability, procurement, BOM, and release authority all stay
  false. The 8.90 mm actuation linkage, positive-M0 retraction linkage,
  SCCG5-10 retention load/wear qualification, nominal 2 mm tolerance stack,
  active/parked transition sweeps, occurrence route clearances, and 5.52 N*m
  mount proof remain blockers.

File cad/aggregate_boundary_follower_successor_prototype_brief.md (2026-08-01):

# Aggregate-boundary follower successor prototype CAD brief

- Model: isolated positive-volume successor-follower review rack. Four
  identity-specific modules represent the selected placement-trade topology:
  an M0-owned re-datumed XYZ stage, yaw/elevation compliance, a polished C1
  guide cartridge, and a mechanically separate aggregate-normal preload leaf
  and shoe.
- Task type: new review-only prototype. It is deliberately not imported by
  `assembly.py`, the player, the selected replacement carriage, any BOM, or
  any release source.
- Units and authority frame: millimetres in the active-stator local frame,
  where +X is radial/outward, +Y is tangential, and +Z is the stator axis. At
  M0 home, `machine=(-local_y, local_z, 95-local_x)`.
- Source contract: fail closed against
  `out/reports/aggregate_boundary_follower_placement_trade.json`; the report
  must retain its internal canonical SHA, selected topology, four identities,
  exact centre bounds, and false physical/release authority.
- Exact identity data: copy every active-local target datum, min/max centre
  bound, and tangent datum from the placement trade without rounding. The
  STEP uses a documented 2 x 2 review-rack display transform; tiny positive-
  volume min/max witnesses are placed by `(active point - active datum)` so
  the exact identity spans remain inspectable and invertible without claiming
  assembly placement.
- Common stage capacity: model at least 1.3822561230042538 x
  2.233484956719163 x 0.9733701456993078 mm XYZ centre travel. The prototype
  uses 1.50 x 2.40 x 1.10 mm and explicit rail, moving bridge, and hard-range
  witness geometry at the neutral pose.
- Orientation capacity: model at least +/-53.23669873274605 degrees yaw and
  +/-9.086049191773341 degrees elevation around each identity datum. The
  prototype uses visible +/-55 degree yaw stops and +/-10 degree elevation
  stop tabs. These are geometry envelopes, not a tolerance/load proof.
- Guide cartridge: one positive-volume polished open-channel cartridge per
  identity. Its review centreline is straight--R3 quarter arc--straight with
  tangent-continuous joins; the shell has a complete loading opening. Each
  cartridge is posed from the identity's exact guide-tangent datum. It is a
  topology prototype only, not a positive-volume surface proved over all
  4,704 analytic cases.
- Preload: one separate spring-leaf body and one separate polished shoe per
  identity. The shoe direction uses the datum radial aggregate-normal witness
  `(datum_X, datum_Y, 0)` normalized. No leaf force, stress, fatigue, wear,
  thermal, or retention claim is made.
- Carrier-floor relief: one positive-volume floor coupon per module is cut by
  an R5.00 spherical exclusion about the target centre. This targets 2.00 mm
  material clearance around the conservative R3 envelope and is intentionally
  separate from the selected carrier. It does not prove the complete carrier,
  fastener, stage, or transition collision envelope.
- Export: source `cad/aggregate_boundary_follower_successor_prototype.py`;
  STEP and manifest under `out/review/`; audit reports under `out/reports/`;
  required orthographic/iso snapshots under `out/review/snapshots/`.
- Validation targets: four modules; positive volume; single-solid custom
  leaves; exact report-bound datums/bounds; modeled travel and angle capacity;
  C1 tangent continuity; separate guide/leaf/shoe bodies; R5 relief cutter;
  source/report/STEP hash bindings; baseline STEP refs/facts/planes/positioning;
  and reviewed multi-view snapshots.
- Explicit blockers: full 4,704-case positive-volume guide surface, mechanism
  collision sweeps at all XYZ/yaw/elevation combinations, flexure sizing,
  preload force/stress/fatigue, guide finish and wear qualification, tolerances,
  fasteners/retention, assembly placement, wire route, dynamic snag/sag, build
  process, procurement, BOM, production, and release.

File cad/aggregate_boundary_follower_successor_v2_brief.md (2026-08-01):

# Aggregate-boundary follower successor V2 CAD brief

- Model: an isolated, active-local replacement for the failed V1 review-rack
  follower.  It retains one M0-owned 6061 U-carrier, puts four handed XYZ
  compliance pods on the two outboard carrier rails, carries each guide on a
  keyed boom, and provides a two-axis bearing gimbal, a replaceable polished
  PEEK C1 guide, and a mechanically independent normal-preload leaf and shoe.
- Authority: review-only.  This source is not imported by `assembly.py`, the
  animation/player, the selected integrated-adapter release, the BOM, or any
  manufacturing release.  Integration remains fail-closed until the exact
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

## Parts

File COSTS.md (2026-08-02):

# Cost status

The published [`bom.csv`](bom.csv) contains 46 physical line items. As of the
project's July 2026 price checks, 36 rows have numeric planning values and 10
remain unpriced.

## Numeric planning subtotal

| Category | Subtotal (USD) |
| --- | ---: |
| Motion | $1,124.76 |
| Required 36 V supply candidate | $199.00 |
| Structure | $97.00 |
| Assembly consumables | $87.79 |
| Tensioner | $26.24 |
| Optional controller integration | $25.00 |
| Printing material | $13.99 |
| **Current numeric subtotal** | **$1,573.78** |

This is a planning lower bound, not an expected delivered total. It includes
a conditional `$199` M2 driver candidate and a `$50` pulley-machining
allowance that is not a supplier quote.

## Unpriced required or job-dependent rows

- MIC6 carriage plate from the release DXF
- counterweight fastener packs
- one-piece machined PEEK flyer guide and bell
- front/rear machined PEEK stator caps
- front/rear machined PEEK active-sector guides
- machined 6061-T6 active-sector yoke
- delivered USD cost for the stock NBK D10 pulley
- six serialized ASTM-B777 tungsten balance trims
- winding wire
- Nomex slot insulation

The subtotal also excludes shipping, tax, import charges, refreshed pack
pricing, machine-shop minimums, inspection charges, mains enclosure and
wiring, protective devices, emergency-stop hardware, and the cost of closing
physical qualification gates.

The stricter machine-readable release catalog currently classifies only
`$420.28` as annotated order-ready known-current cost, `$199.00` as
conditional known-current cost, and `$50.00` as a planning allowance. That
catalog intentionally reports `complete_machine_total_available: false`.
Until the ten unpriced rows are quoted and the manual BOM is reconciled with
the release catalog, the project does not have a defensible complete expected
build cost.

Before purchasing, regenerate or review `hardware/orders/full_order.csv`,
refresh every vendor price, and record quotes separately from allowances.

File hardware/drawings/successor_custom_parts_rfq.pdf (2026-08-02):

SUCCESSOR PEEK WIRE-CONTACT PARTS | DRAWING WG-010 REV A 2026-07-11 PAGE 1/3
STEP PART | QTY | MATERIAL | CONTROLLED FUNCTION
flyer_peek_guide_bell | 1 | Natural unfilled PEEK | One-piece ID0.60 polished bore, R3.25 root elbow and integral exit bell
stator_short_leadin_cap_front | 1 | Natural unfilled PEEK | Front 24-sector cap with open short lead-ins; paired M2 retention
stator_short_leadin_cap_rear | 1 | Natural unfilled PEEK | Rear 24-sector cap with open short lead-ins; paired M2 retention
active_sector_peek_guide_front | 1 | Natural unfilled PEEK | M0-following front capture shoe with open bowls and keyed pads
active_sector_peek_guide_rear | 1 | Natural unfilled PEEK | M0-following rear capture shoe with open bowls and keyed pads

### RFQ AND RELEASE BLOCKERS

1. The paired STEP is the exact shape authority. Do not close, bridge, or simplify any polished open wire channel.
2. Quote only natural unfilled PEEK. State exact resin grade, filler declaration, lot certificate, machining process, achievable finish, and dimensional inspection method.
3. Wire-contact surfaces require supplier DFM review, burr-free polish, and later abrasion, dielectric, varnish and 60 N hot coupons. This packet is not production authorization.
4. No price or supplier is selected. Return a marked-up drawing and quote before any order state may advance.
UNITS: mm | UNLESS NOTED: remove burrs; break non-contact edges 0.2 max | SHAPE AUTHORITY: out/custom/successor/step/flyer_peek_guide_bell.step

SUCCESSOR MACHINED STRUCTURE | DRAWING M2-010 REV B 2026-07-12 PAGE 2/3
STEP PART | QTY | MATERIAL | CONTROLLED FUNCTION
active_sector_aluminum_yoke | 1 | Certified 6061-T6 only | One-solid keyed M0 carriage yoke; four M4 tower stacks and four M3 guide stacks

### RFQ AND RELEASE BLOCKERS

1. Preserve all keyed datums and M3/M4 hole positions from the yoke STEP. No decorative substitutions are allowed.
2. Supplier must confirm certified 6061-T6 and return heat treatment, machining tolerance, concentricity, runout, balance and surface-treatment proposal. No alloy or temper substitution is pre-authorized; prices remain TBD.
3. The selected flyer pulley is the separate stock NBK P30-3GT-BLP-6C-10 and is not a custom machined part in this packet.
4. All M3 and M4 yoke fasteners are ordered separately. Motor-side BNW witnesses remain outside this packet and have purchase quantity zero.
UNITS: mm | UNLESS NOTED: remove burrs; break non-contact edges 0.2 max | SHAPE AUTHORITY: out/custom/successor/step/active_sector_aluminum_yoke.step

SERIALIZED ASTM-B777 BALANCE TRIMS | DRAWING M2-011 REV A 2026-07-11 PAGE 3/3
STEP PART | QTY | GEOMETRY | SOLVED CONTROL
balance_b777_rear_1 | 1 | Rear annular stack | Solved axial length 1.537534 mm
balance_b777_rear_2 | 1 | Rear annular stack | Solved axial length 0.600000 mm
balance_b777_rear_3 | 1 | Rear annular stack | Solved axial length 0.630832 mm
balance_b777_rear_4 | 1 | Rear annular stack | Solved axial length 1.568040 mm
balance_b777_front_left | 1 | OD6 / ID2.2 annulus | Common thickness 1.502168 mm
balance_b777_front_right | 1 | OD6 / ID2.2 annulus | Common thickness 1.502168 mm

### MATERIAL, WEIGHING AND RELEASE BLOCKERS

1. Quote ASTM-B777 tungsten heavy alloy but state grade, certified density, chemistry, lot and achievable dimensional tolerance. No grade substitution is pre-authorized.
2. Machine each serialized trim to its own STEP. Deburr without rounding bearing faces or changing the annular bore. Weigh each finished trim and record actual mass and serial number.
3. Four rear trims use separate printed retainers, M3x6 countersunk screws and 94459A130 inserts. Two front trims use M2x8 screws, washers and standard M2 inserts.
4. The six solved dimensions are nominal digital balance values. Final installed G2.5 balance, retention pull tests and hot 300 RPM endurance remain mandatory before use.
UNITS: mm | UNLESS NOTED: remove burrs; break non-contact edges 0.2 max | SHAPE AUTHORITY: out/custom/successor/step/balance_b777_rear_1_rear_left.step

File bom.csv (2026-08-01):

category | item | spec | qty | unit_usd | ext_usd | sourcing | cad_model_source
motion | NEMA17 closed-loop stepper motor/driver sets (M0 M1) | StepperOnline 1-CL42T-S05-V41; each kit includes 17HS19-2004D-E1K motor + CL42T-V41 driver + programming cable; 52 Ncm holding; 68 mm body; 5x24 mm shaft; 1000 PPR encoder | 2 | 48.86 | 97.72 | StepperOnline exact live kit https://www.omc-stepperonline.com/1-axis-closed-loop-stepper-cnc-kit-52ncm-73-64oz-in-nema-17-motor-driver-1-cl42t-s05-v41 | authoritative vendor STEP models/upgrades/17HS19-2004D-E1K.step; official 24 V dynamic curve saved alongside; loose cable excluded from rigid collision envelope
motion | NEMA17 motor/encoder (M2) | Leadshine CS-M21708; 0.8 N m holding; 83 mm body; 5 mm D shaft; 1000-line encoder; official 36 V / RMS 2.5 A torque curve | 1 | 199.00 | 199.00 | Leadshine official current Add-to-Cart price verified 2026-07-11 https://www.leadshine.com/product-detail/closed-loop-stepper-drive/closed-loop-stepper/CS-M21708.html | authoritative vendor STEP cad/models/upgrades/CS-M21708.STEP plus provenance-bound installed cableless derivative CS-M21708_cableless.step; exact curve and mechanical PDF saved alongside
motion | Conditional closed-loop stepper driver candidate (M2) | Leadshine CS-D508; official manual lists CS-M21708 as tested compatible; 20-50 VDC; 0.5-8.0 A peak; exact 3.5 versus 3.6 A peak setting for the 36 V / RMS 2.5 A curve and hot 300 RPM proof remain blocked | 1 | 199.00 | 199.00 | CONDITIONAL ONLY - Leadshine official current Add-to-Cart price verified 2026-07-11 https://www.leadshine.com/product-detail/CS-D508.html; do not order for production until the exact curve configuration and hot proof close | cad/models/upgrades/Leadshine_CS-D508_manual_v1.0.pdf SHA256 0faaf40eebe24203511b50b3e3658bec9fc298b13221031759b84d3eb9bdba60; CS1-D503S and CL42T-V41 are not valid substitutes for the bound M2 curve
motion | Linear rail MGN12H + block | ABRA MP-LR12H-150; 150 mm x 12 mm MGN12 rail + 1 MGN12H long block each; pre-lubricated | 2 | 29.98 | 59.96 | ABRA Electronics exact live in-stock assembly https://abra-electronics.com/3d-printers-en/linear-movement/linear-rails/mgn/mp-lr12h-150.html | REAL HIWIN vendor STEPs models/upgrades/mgn12*.step define the conservative reference envelope; receipt inspection must confirm H13 block 45.4x27 M3 pattern 20x20 rail 12x8 pitch25
motion | Lead screw T8x8 4-start | Custom Ø8 x 188 mm screw with native 30 mm smooth Ø8 journal; Zyltech HW-SC-SMALLFL-P Delrin anti-backlash set configured T8x8 | 1 | 20.95 | 20.95 | Dimensioned custom screw RFQ plus exact Zyltech nut set https://www.zyltech.com/delrin-anti-backlash-nut-small-flange-size-and-hole-pattern-t8x8-or-t8x2/; choose T8x8 2 mm pitch 4-start 8 mm lead | custom screw STEP/PDF plus supplier-drawing main nut secondary nut and spring swept envelopes; receiving contract limits configured nut length to 22.4 mm
motion | Beam coupling 5x8 | Ruland PCMR22-8-5-A zero-backlash clamp coupling; 8x5 bores; Ø22.2 x 27; 0.45 Nm reversing dynamic capacity | 2 | 59.80 | 119.60 | Ruland exact live order line https://www.ruland.com/pcmr22-8-5-a.html; 0-2 day production lead shown 2026-07-10 | step.parts Ø24x32 reference STEP retained as conservative collision envelope; exact 12.5 mm shaft engagements checked
motion | Bearing 608ZZ | 8x22x7 stainless double-shielded; 2 installed + 1 spare | 3 | 1.00 | 3.00 | AMPEC S608-ZZ from Bearings Direct exact order line | step.parts bearing_608zz (sha256-verified); purchased material is stainless
motion | Bearing 6001ZZ | 12x28x8 double-shielded | 2 | 1.50 | 3.00 | AMPEC 6001-ZZ from Bearings Direct exact order line | step.parts bearing_6001_zz_shielded_simple (sha256-verified)
motion | Bearing 623ZZ | 3x10x4 miniature double-shielded bearing for dancer pulley | 1 | 1.50 | 1.50 | AMPEC 623-ZZ from Bearings Direct exact order line | parametric exact envelope in cots.py
motion | Bearing 688-2RS | 8x16x5 rubber-sealed bearing for M0 fixed screw end | 1 | 2.00 | 2.00 | AMPEC 688-2RS from Bearings Direct exact order line; do not substitute a 4 mm-wide B688ZZ | parametric exact 8x16x5 envelope in cots.py
motion | M0 fixed-end retention set | Ø8 clamp collar OD18x9 with Ø11.8 inner-race pilot + 8.1IDx12ODx1 shim + DIN472-16 ring | 1 | 6.00 | 6.00 | generic metric collar/shim/ring; verify collar pilot or turn from stock | all three components modeled separately; printed housing has Ø16.1 seat and Ø16.8x1.1 groove
motion | M1 spindle retention set | 21.8ODx18.2IDx16 outer spacer + 17.8ODx8.05ID inner spacers 16 and 12 long + Ø8 collar 16ODx9 + 2 DIN472-22 rings | 1 | 8.00 | 8.00 | generic metric turned spacers/collar/rings | all six components modeled separately and located against the 608 races
motion | M2 flyer bearing retention set | 27.8ODx20IDx11 outer spacer + 18ODx12.05ID inner spacers 11 and 4 long + 0.5 shim + DIN472-28 ring | 1 | 8.00 | 8.00 | generic metric turned spacers/shim/ring | all five components modeled separately; flyer block includes Ø28.1 seat shoulder and Ø29.4x1.3 groove
motion | 30T 3GT motor pulley with conditional BNW machining | NBK P30-3GT-BLP-6C-5 stock split-clamp pulley; 5 mm bore; 6 mm belt; BNW adds two supplied set-screw holes at 90 degrees but exact delivered size location drawing quote and reversing retention proof remain open | 1 | 50.00 | 50.00 | CONDITIONAL RFQ_READY_FOR_SUPPLIER_RESPONSE_ONLY - send docs/rfq/m2_p30_d5_bnw_rfq_A.md revision M2-P30-D5-BNW-RFQ-A to NBK; preserve the existing 50 USD planning allowance only because it is not a quote; configured drawing complete part number set-screw details price and lead time are required before any order | immutable official stock STEP cad/models/upgrades/NBK_P30-3GT-BLP-6C-5_AP214.step SHA256 996449b7d9ec7703e7b38c6f75eff00a1174e3e1f088c05f0f1460b205169df9; M3x12 BNW witnesses are not delivered material; reversing coupon must reach the current 0.471456 N m 2x threshold
motion | 3GT closed belt 210-3GT-6 | 210 mm pitch length x 6 mm wide for the frozen 30T:30T exact 1:1 drive; 1 installed + 1 spare | 2 | 11.14 | 22.28 | Gates Unitta Asia 210-3GT-6 through MISUMI US exact configured line at 11.14 USD each verified 2026-07-11 https://us.misumi-ec.com/vona2/detail/221004924969/?HissuCode=210-3GT-6 | modeled exact pitch-line envelope in the integrated M2 successor; no obsolete 200-2GT artifact is release authority
motion | Ounuowei C8-ER11A-100L holder + MariTool ER11 metric set | Ø8 shank x 100 holder with exact 1-7 mm by 0.5 mm ER11 collet set | 1 | 264.75 | 264.75 | Ounuowei catalog RFQ for C8-ER11A-100L (18.00 planning allowance) plus current 246.75 MariTool ER11-13PIECE cart price; inspect received nut OD | verified parametric models/upgrades/er11_c8_hifi.step from Ounuowei catalog and DIN/REGO-FIX dimensions (er11.report.md)
motion | Custom Ø8 shaft socket holder | Ø8x100 shank + OD16x16 clamp body + ID8.10x14 socket + 2x M4x5 cup-point set screws; exact Ø8.00 shaft endpoint only | 1 | 60.00 | 60.00 | custom machine from project STEP/PDF; no supplier SKU claimed | out/custom/step/shaft8_socket_holder.step + output/pdf/shaft8_socket_holder.pdf
structure | 2020 T-slot extrusion | cut set: 2x450 3x180 2x280 2x235 1x305 mm (2775 mm total) | 1 | 18.00 | 18.00 | MISUMI HFS5-2020 configured lines: HFS5-2020-450 x2; -180 x3; -280 x2; -235 x2; -305 x1 | parametric real B-type slot-6 profile
structure | Custom 6061-T6 stock-D10 flyer shaft | L79.00 shaft: full 18.50 mm OD9.991-10.000 h6 / ID6.000-6.030 round seat; 3.00 mm polished transition to ID9.000-9.050; OD11.980-12.000 main span; two arm flats only; R0.5 mouths; Rev D | 1 | 18.00 | 18.00 | custom machine RFQ planning allowance pending quote; stock-pulley fit controlled IDs and polished transition inspection required | out/custom/step/flyer_shaft_d10_id6_to_id9_l79.step generated by cad/custom_parts.py; output/pdf/flyer_shaft_d10_id6_to_id9_l79.pdf M2-001 Rev D
structure | 0.250 inch MIC6 carriage plate | SendCutSend ALUMIC6-250 MIC6 cast aluminum plate; 0.250 inch / 6.35 mm; 148 x 87.5 mm flat fiber-laser-cut profile; quantity 1 | 1 |  |  | UPLOAD_READY_UNPRICED; upload the release DXF with material SKU ALUMIC6-250 and no secondary services; current SendCutSend quote and checkout price are excluded from the planning subtotal | cad/fabricated_carriage.dxf is the cut authority; cad/fabricated_carriage.step is the thickness reference; out/reports/sendcutsend_carriage.json passes all 8 preflight checks for the assumed upload context
structure | MISUMI frame brackets | HBKTST5 5-series slot-6 brackets with audited screw/T-nut stacks | 15 | 0.60 | 9.00 | MISUMI HBKTST5 exact order line | all 15 brackets and their hardware are placed in the assembly audit
structure | 35 mm machine-foot stack | Elesa 432001 OD20x17 M5x6 foot + Würth 970180581 M5 F/F AF8x18 standoff + ISO4026 M5x12 set screw; 4 stacks | 4 | 10.00 | 40.00 | exact Reiman Elesa line + Farnell 2884560 standoff + Accu SSF-M5-12-A2; planning allowance excludes international shipping | three separate modeled occurrences per corner plus shifted HNTA5-5; set screw projection 4.8 +/-0.1 preserves y=-260 support plane and 8.35 mm M1 motor clearance
structure | T-nut + fastener schedule | 56 unique M2/M2.5/M3/M4/M5/M8 screw nut washer insert and T-nut SKUs after selecting the stock D10 split-clamp pulley | 1 | 12.00 | 12.00 | generated exact package schedule in out/order/hardware_order.csv; all eight previously unresolved lines now have exact cart-ready McMaster SKU and pack mappings; current pack prices and line-specific fulfillment remain unasserted and must be rechecked at checkout | the supplied NBK M2 clamp bolt belongs to the purchased pulley; obsolete flyer-side M3x6 set screws and BNW witnesses have purchase quantity zero
tensioner | Omron D2F-01L2-D3 home microswitch | SPDT hinge roller; 2x OD2.00 +0.12/0 mounting holes on 6.50 mm centers; solder terminals; 1 installed + 1 spare | 2 | 2.87 | 5.74 | DigiKey Z4701-ND exact active stocked order line https://www.digikey.com/en/products/detail/omron-electronics-inc-emc-div/D2F-01L2-D3/5236578 | manufacturer-dimensioned parametric model models/upgrades/omron_d2f_01l2_d3.step; mount and flag revised to controlled Omron interface
tensioner | Fixed ceramic eyelet | polished ID4 x OD9 x 3 mm entry guide; 1 installed + 1 spare | 2 | 1.00 | 2.00 | purchase blocked: Stanford Advanced Materials AC10042 proves only OD9 and KEIR offers custom polished guides; neither proves an exact order line https://www.samaterials.com/item/ac10042-alumina-ceramic-ring-aluminum-oxide-ring-al2o3-ring-99-dia-9-mm.html | one entry-guide annulus plus one fragile spare; the retired flyer-tip toroid is replaced by the one-piece PEEK guide/bell
tensioner | Dancer extension spring | Lee Spring LEM050AB 01 M; OD3.5 wire0.5 free9.5 initial1.77N rate2.35N/mm max12N | 1 | 3.00 | 3.00 | Lee Spring LEM050AB 01 M; exact official order line | selected geometry and equilibrium sweep in dancer_loads.json
tensioner | Dancer pivot hardware | McMaster 96654A127 OD5x10 shoulder/M4x5 thread + M4 washers + M4 nyloc | 1 | 4.00 | 4.00 | McMaster 96654A127 plus hardware order schedule | separate placed solids and fastener-stack audit
tensioner | Dancer pulley axle | McMaster 90265A420 OD3x16 shoulder/M2.5x4 thread + DIN988 shims + M2.5 nyloc | 1 | 3.00 | 3.00 | McMaster 90265A420 plus hardware order schedule | separate grooved pulley bearing shims and retention hardware modeled
tensioner | Felt compression spring | McMaster 94125K614 OD9.25 ID6.75 spring selected for calibrated 1-10N drag range | 1 | 2.00 | 2.00 | McMaster 94125K614 pack of 5 | preload sweep and installed envelope audited in felt_loads.json
tensioner | Felt tensioner hardware | DIN976 M4x55 stud + OD20 backing discs + McMaster 91116A130 thrust washer + DIN315 M4 wingnut | 1 | 3.00 | 3.00 | exact hardware order schedule; stud cut from McMaster 90024A221 | each stack component modeled and thread engagement audited
tensioner | Felt washers Ø20 | wool felt wire-drag pads; 2 installed + 4 spares | 6 | 0.25 | 1.50 | locally cut from exact McMaster 8341K31 plain-back F5 95 percent wool felt sheet; 12x12x1/8 inch https://www.mcmaster.com/product/8341K31/ | separate annular washer envelopes modeled; do not substitute adhesive-backed 8341K11
tensioner | Spool axle M8 x 75 | shoulder bolt or ground shaft + thin thrust washers + locknut/collars | 1 | 2.00 | 2.00 | generic | axle bore modeled in spool_bracket
flyer | Counterweight hardware | 4x McMaster 92125A126 / ISO10642 M3x6 rear screws + 4x 94459A130 M3 short inserts; 2x ISO4762 M2x8 front screws + 2x ISO7089 M2 washers + 2x 94459A120 standard M2 inserts | 1 |  |  | CART_READY_FOR_QUALIFICATION: all exact McMaster SKU and pack mappings are verified; current price and fulfillment are not asserted and must be rechecked at checkout; do not reuse the retired M3x12/three-washer stack | all six fastener stacks are modeled in positive printed material and bound by the integrated candidate; insert pull and hot endurance coupons remain open
flyer | One-piece PEEK flyer guide and exit bell | natural virgin unfilled PEEK one-solid guide; ID0.60 polished passage; integral root elbow and exit bell; 3x M2x6 retention | 1 |  |  | RFQ_READY_FOR_QUOTE_ONLY; hash-bound STEP/drawing/CSV and supplier-return questions are complete; ORDER AND PRODUCTION BLOCKED pending exact resin grade/lot DFM finish inspection quote insert pull abrasion dielectric varnish 60 N hot-load flexible-wire and hot-endurance results | out/custom/successor/step/flyer_peek_guide_bell.step + output/pdf/successor_custom_parts_rfq.pdf + out/custom/successor/successor_rfq.csv; obsolete ceramic toroid and PTFE elbow are not release parts
wire_path | Short-leadin PEEK stator caps | matched front + rear natural virgin unfilled PEEK caps from one lot; 24 open short lead-ins per end and one shared 3x M2x20 through-fastener set | 2 |  |  | RFQ_READY_FOR_QUOTE_ONLY; hash-bound paired STEP/drawing/CSV and supplier-return questions are complete; ORDER AND PRODUCTION BLOCKED pending exact resin grade/lot DFM finish inspection quote paired fit abrasion dielectric hot-varnish and launch-matrix results | out/custom/successor/step/stator_short_leadin_cap_front.step and _rear.step + output/pdf/successor_custom_parts_rfq.pdf + out/custom/successor/successor_rfq.csv
wire_path | Active-sector PEEK terminal guides | matched front + rear M0-following M1-static natural virgin unfilled PEEK guides from one lot; 4x M3x14/washer/short-insert clamp stacks total | 2 |  |  | RFQ_READY_FOR_QUOTE_ONLY; hash-bound paired STEP/drawing/CSV and supplier-return questions are complete; ORDER AND PRODUCTION BLOCKED pending exact resin grade/lot DFM finish inspection quote guide-key fit insert pull abrasion flexible-wire launch-matrix and hot-endurance results | out/custom/successor/step/active_sector_peek_guide_front.step and _rear.step + output/pdf/successor_custom_parts_rfq.pdf + out/custom/successor/successor_rfq.csv
structure | Active-sector aluminum yoke | rev6 one-solid keyed outboard coil-bypass carriage yoke in certified 6061-T6 with four M4x10/washer/short-insert tower stacks; no alloy/temper equivalent pre-authorized | 1 |  |  | RFQ_READY_FOR_QUOTE_ONLY; hash-bound STEP/drawing/CSV and supplier-return questions are complete; default-job rigid geometry and the complete raw rigid sweep pass; ORDER AND PRODUCTION BLOCKED pending DFM 6061-T6 certificate commitment first-article inspection quote flexible-conductor launch-matrix and physical gates | out/custom/successor/step/active_sector_aluminum_yoke.step + output/pdf/successor_custom_parts_rfq.pdf drawing M2-010 Rev B + out/custom/successor/successor_rfq.csv; collision revision active-sector-r39p2__physical-bell-root-sleeve-six-slug__L79-stock-D10-P30__short-cap-leadins__rev6-front-plane-outboard-coil-bypass-yoke
motion | Stock NBK 30T 3GT flyer pulley | P30-3GT-BLP-6C-10; D10 split clamp; 6 mm belt; supplied M2 bolt at 0.5 N m; A2017 body; 28 g; axial J 3.0e-6 kg m2 | 1 |  |  | CART_READY_REFERENCE_ONLY; official NBK Japan page listed this exact MPN in stock with cart action at JPY 5060 before tax / JPY 5566 including tax on 2026-07-12; delivered USD cost and shipping are not asserted; INSTALLATION AND MOTION AUTHORIZATION BLOCKED pending delivered-bore/bolt inspection reversing slip belt-pretension shoulder six-trim balance and hot-endurance proof | official NBK product row https://www.nbk1560.com/products/pulley/timingpulley/3GT-BLP-6C/P30-3GT-BLP-6C/ + immutable vendor STEP cad/models/upgrades/NBK_P30_D10_download/P30-3GT-BLP-6C-10.stp SHA256 780110e1d59a988661f5ae80e9ebbe5d2eb324b9037d33a481809c939fa4c9f1
flyer | Six serialized ASTM-B777 balance trims | four rear annular slugs with printed three-post retainers + two front OD6/ID2.2 annular trims; all six dimensions are solved at the immutable 18.49 g/cm3 balance-design density | 6 |  |  | RFQ_READY_FOR_QUOTE_ONLY; hash-bound six-STEP/drawing/CSV and supplier-return questions are complete; preferred material baseline McMaster 5995N71/5995N72 ASTM B777 1/2in ultra-dense rod with traceable lot certificate; ORDER AND PRODUCTION BLOCKED pending supplier class/certified 18.49 g/cm3 density lot quote tolerances measured serial masses G2.5 balance pull tests and hot endurance | six individual out/custom/successor/step/balance_b777_*.step files + output/pdf/successor_custom_parts_rfq.pdf + out/custom/successor/successor_rfq.csv; any density substitution requires a new balance solve and six new STEP files; four PETG retainers are separate print jobs
wire | Default winding wire | Remington 32SNSP.125; 32 AWG single-build 155 C magnet wire; 0.22352 mm supplier nominal finished OD; 2 oz / 611 ft spool; accepted conservative measured job input 0.220-0.235 mm | 1 |  |  | Remington Industries 32SNSP.125 exact order line https://www.remingtonindustries.com/magnet-wire/magnet-wire-32-awg-enameled-copper-9-spool-sizes/; job-consumable price excluded from machine estimate | measure at no fewer than five separated locations; use the conservative maximum including instrument uncertainty; regenerate every job artifact before winding
wire | Default stator slot insulation | DuPont Nomex Type 410 5 mil; BAE Wire INNMX410005S; 24 x 36 inch sheet; 0.127 mm supplier nominal; accepted conservative measured installed job input 0.120-0.140 mm | 1 |  |  | BAE Wire exact order line https://www.baewire.com/NOMEX-TYPE-410-005-24-X-36-SHEETS-p/innmx410005s.htm | measure the formed installed liner coupon at no fewer than five locations; use the conservative maximum including instrument uncertainty; regenerate every job artifact and prove protected core edges
electronics_required_condition | Required regulated 36 V M2 supply condition | Selected Leadshine LSP-360-36; regulated 36 VDC; 10 A continuous; 18 A peak; 360 W; selectable 92-138 or 184-276 VAC input; 215x115x30 mm | 1 | 199.00 | 199.00 | CONDITIONAL CART CANDIDATE ONLY - Leadshine official current Add-to-Cart price verified 2026-07-11 https://www.leadshine.com/product-detail/LSP-360-36.html; no PSU is order-authorized for production until mains enclosure protection disconnect PE bonding mounting wiring thermal and back-EMF integration close | exact SKU capacity envelope and official price are pinned; set the input selector for site mains before energizing; 24 V must not be used for the selected M2 release curve
electronics_optional | Optional controller integration | board implementing M{id}A/M{id}P/ESTOP serial protocol | 1 | 25.00 | 25.00 | Goal1 firmware/electronics-internals scope exclusion; STM32 NUCLEO-G431KB / DigiKey 497-19489-ND is an unreleased candidate requiring level shifting isolation pinout ESTOP alarms and connectors | out of mechanical CAD scope
assembly_consumable | Fixed-eyelet and shaft-wrap-sleeve adhesive | Henkel LOCTITE EA 445 MPN 209717; ten premeasured 4 g mixer cups; clean abrade wash coat both faces assemble within 5 min immobilize and cure 72 h at 21 C | 1 | 80.79 | 80.79 | EIS LOC21425 exact available-to-order case https://www.eis-inc.com/product/epoxy-adhesive-loc21425 | for fixed ceramic eyelets and the interphase shaft-wrap sleeve only; keep adhesive off polished wire-contact surfaces; qualify scrap PETG-to-alumina and steel-to-alumina bonds before production
assembly_consumable | Foot-stud threadlocker | LOCTITE 243 medium-strength anaerobic threadlocker; one 0.02 fl oz single-use capsule for four M5x12 studs | 1 | 7.00 | 7.00 | McMaster 91458A114 exact capsule; planning allowance pending cart quote | degrease and bond only the 7.2 mm standoff engagement; set 4.8 +/-0.1 mm projection; wipe excess and cure 24 h before loading
print | PETG filament | Inland PETG+ PETG+175SB1 black 1.75 mm 1 kg; planning mass TBD across 21 printed parts including the solid-infill successor arm and four balance retainers | 1 | 13.99 | 13.99 | Micro Center SKU 151506 exact live line https://www.microcenter.com/product/626528/inland-175mm-black-petg-3d-printer-filament-1kg-spool-%2822-lbs%29 | 21 parts in out/stl/ after regeneration; dry and use the same spool for the qualification coupon and production
 |  |  |  | TOTAL: | 1573.78 | numeric planning subtotal only; includes conditional CS-D508 and LSP-360-36 candidate prices plus the inherited BNW allowance but authorizes none of them; excludes every unpriced RFQ-ready/TBD successor custom part which remains order- and production-blocked; the unquoted SendCutSend MIC6 carriage plate; fastener delta; and any actual NBK BNW quote delta

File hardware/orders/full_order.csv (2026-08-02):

id | class | scope | category | description | design_status | purchase_status | authorization_status | rfq_submission_status | order_authorized | production_authorized | required_qty | spare_qty | pack_qty | packages_to_order | order_qty | uom | supplier | supplier_sku | receiving_contract_json | checkout_condition
kit-m0-m1-1-cl42t-s05-v41 | cots | machine | motion | M0/M1 closed-loop NEMA17 motor driver and cable kits | selected | cart_ready | order_ready |  |  |  | 2 | 0 | 1 | 2 | 2 | each | StepperOnline | 1-CL42T-S05-V41 | {}
driver-m0-m1-cl42t | electronics | excluded | electronics | Separate closed-loop stepper drivers for M0 and M1 | not_applicable | excluded | excluded |  |  |  | 0 | 0 | 1 | 0 | 0 | each |  |  | {}
motor-m2-leadshine-cs-m21708 | cots | machine | motion | Leadshine CS-M21708 M2 NEMA17 motor with 1000-line encoder | selected | cart_ready | order_ready |  |  |  | 1 | 0 | 1 | 1 | 1 | each | Leadshine | CS-M21708 | {}
driver-m2-leadshine-cs-d508-conditional | electronics | machine | electronics | Selected Leadshine CS-D508 closed-loop M2 driver; hardware order-ready, production current configuration remains a commissioning gate | selected | cart_ready | order_ready |  |  |  | 1 | 0 | 1 | 1 | 1 | each | Leadshine | CS-D508 | {"commissioning_supply_vdc":36.0,"encoder_lines":1000,"exact_model":"CS-D508","input_voltage_vdc":{"maximum":50.0,"minimum":20.0},"production_configuration_requires_manufacturer_or_dyno_proof":true,"software_peak_current_A":{"candidate_lower":3.5,"candidate_upper":3.6,"released":null}}
linear-rail-mgn12h-150 | cots | machine | motion | 150 mm MGN12 rail with MGN12H block | selected | cart_ready | order_ready |  |  |  | 2 | 0 | 1 | 2 | 2 | assembly | ABRA Electronics | MP-LR12H-150 | {}
t8-antibacklash-flange-nut | cots | machine | motion | T8x8 four-start POM anti-backlash flange nut | selected | cart_ready | order_ready |  |  |  | 1 | 0 | 1 | 1 | 1 | each | ZYLtech Engineering | HW-SC-SMALLFL-P / T8x8 option | {"configured_installed_length_max_mm":22.4,"inspection":"Confirm both 15 mm Delrin halves, main flange OD22 x 4 with four M3 holes on PCD16, secondary flange OD14 x 4, free sliding engagement on the released screw, and backlash removal while the complete installed set remains within the 22.4 mm reserved axial envelope.","required_option":"T8x8 (2 mm pitch, 4-start, 8 mm lead)"}
t8x8-leadscrew-188-journal30 | custom | machine | motion | T8x8 four-start lead screw, 188 mm, native 30 mm smooth diameter-8 journal | selected | rfq_ready | order_ready |  |  |  | 1 | 0 | 1 | 1 | 1 | each |  |  | {}
beam-coupling-5x8-24x32 | cots | machine | motion | Ruland 8 mm to 5 mm four-beam clamp coupling, OD22.2 x 27 mm | selected | cart_ready | order_ready |  |  |  | 2 | 0 | 1 | 2 | 2 | each | Ruland Manufacturing | PCMR22-8-5-A | {}
bearing-608zz | cots | machine | bearing | 608ZZ 8x22x7 bearing | selected | cart_ready | order_ready |  |  |  | 2 | 1 | 1 | 3 | 3 | each | Bearings Direct | S608-ZZ | {}
bearing-6001zz | cots | machine | bearing | 6001ZZ 12x28x8 bearing | selected | cart_ready | order_ready |  |  |  | 2 | 0 | 1 | 2 | 2 | each | Bearings Direct | 6001-ZZ | {}
bearing-623zz | cots | machine | bearing | 623ZZ 3x10x4 dancer bearing | selected | cart_ready | order_ready |  |  |  | 1 | 0 | 1 | 1 | 1 | each | Bearings Direct | 623-ZZ | {}
bearing-688-2rs | cots | machine | bearing | 688-2RS 8x16x5 fixed-end bearing | selected | cart_ready | order_ready |  |  |  | 1 | 0 | 1 | 1 | 1 | each | Bearings Direct | 688-2RS | {}
retaining-ring-din472-16 | cots | machine | retention | DIN 472 internal retaining ring for 16 mm bore | selected | cart_ready | order_ready |  |  |  | 1 | 1 | 5 | 1 | 5 | each | McMaster-Carr | 98394A431 | {}
retaining-ring-din472-22 | cots | machine | retention | DIN 472 internal retaining ring for 22 mm bore | selected | cart_ready | order_ready |  |  |  | 2 | 1 | 5 | 1 | 5 | each | McMaster-Carr | 98394A440 | {}
retaining-ring-din472-28 | cots | machine | retention | DIN 472 internal retaining ring for 28 mm bore | selected | cart_ready | order_ready |  |  |  | 1 | 1 | 1 | 2 | 2 | each | McMaster-Carr | 98394A447 | {}
bearing-retention-custom-set | custom | machine | retention | Custom M0, M1, and M2 bearing race spacers, collar, and shim set | selected | rfq_ready | order_ready |  |  |  | 10 | 0 | 1 | 10 | 10 | piece |  |  | {}
motor-pulley-nbk-p30-3gt-blp-6c-5-bnw-conditional | custom | machine | motion | NBK P30-3GT-BLP-6C-5 stock split-clamp pulley with conditional BNW two-set-screw machining | selected | rfq_ready | conditional |  |  |  | 1 | 0 | 1 | 1 | 1 | each | NBK configured-machining RFQ | P30-3GT-BLP-6C-5-BNW | {}
timing-belt-210-3gt-6 | cots | machine | motion | 210 mm pitch-length 3GT timing belt, 6 mm wide | selected | cart_ready | order_ready |  |  |  | 1 | 1 | 1 | 2 | 2 | each | MISUMI US | 210-3GT-6 | {}
spindle-er11-c8-100l | tooling | machine | workholding | Ounuowei C8-ER11A-100L straight-shank collet holder | selected | rfq_ready | order_ready |  |  |  | 1 | 0 | 1 | 1 | 1 | each |  |  | {}
er11-metric-collet-set-1-7 | tooling | machine | workholding | MariTool ER11 13-piece metric collet set, 1-7 mm by 0.5 mm | selected | cart_ready | order_ready |  |  |  | 1 | 0 | 1 | 1 | 1 | set | MariTool | ER11-13PIECE | {}
m1-spindle-custom-d8-c8-100l | tooling | machine | workholding | Custom 4140 prehard socket holder for the exact 8.00 mm shaft endpoint | selected | rfq_ready | order_ready |  |  |  | 1 | 0 | 1 | 1 | 1 | each |  |  | {}
extrusion-hfs5-2020-cut-set | raw_stock | machine | structure | 2020 slot-6 extrusion cut set: 2x450, 3x180, 2x280, 2x235, 1x305 mm; 2775 mm total | selected | cart_ready | order_ready |  |  |  | 10 | 0 | 1 | 10 | 10 | cut_length | MISUMI | HFS5-2020-450 x2; HFS5-2020-180 x3; HFS5-2020-280 x2; HFS5-2020-235 x2; HFS5-2020-305 x1 | {}
foot-stack-elesa-432001-wurth-970180581 | cots | excluded | structure | Foot-stack interface evidence; ordering is carried by the three exact hardware rows | selected | excluded | excluded |  |  |  | 0 | 0 | 1 | 0 | 0 | stack |  |  | {}
flyer-shaft-stock-d10-rev-d | custom | machine | structure | L79.00 hollow flyer shaft with full OD10/ID6 stock-pulley seat, ID6-to-ID9 transition, OD12 main span and two arm flats | selected | rfq_ready | order_ready |  |  |  | 1 | 0 | 1 | 1 | 1 | each |  |  | {}
carriage-plate-mic6-0p250 | sendcutsend | machine | fabricated | 0.250 inch MIC6 carriage plate | selected | upload_ready | order_ready |  |  |  | 1 | 0 | 1 | 1 | 1 | each | SendCutSend | ALUMIC6-250 | {}
endstop-omron-d2f-01l2-d3 | cots | machine | sensor | Omron D2F-01L2-D3 hinge-roller microswitch with solder terminals | selected | cart_ready | order_ready |  |  |  | 1 | 1 | 1 | 2 | 2 | each | DigiKey | Z4701-ND | {}
fixed-ceramic-eyelet-id4-od9 | custom | machine | wire_path | Drawing-controlled polished alumina fixed guide, ID4 x OD9 x 3 mm | selected | rfq_ready | order_ready |  |  |  | 1 | 1 | 1 | 2 | 2 | each |  |  | {}
flyer-guide-peek-one-piece | custom | machine | wire_path | One-piece natural-unfilled-PEEK flyer guide with integral polished exit bell | selected | rfq_ready | blocked | ready | False | False | 1 | 0 | 1 | 1 | 1 | each |  |  | {}
stator-short-leadin-peek-cap-pair | custom | machine | wire_path | Front and rear natural-unfilled-PEEK stator caps, each with 24 two-branch short-leadin sectors (48 open branch grooves per cap) | selected | rfq_ready | blocked | ready | False | False | 2 | 0 | 1 | 2 | 2 | each |  |  | {}
active-sector-peek-guide-pair | custom | machine | wire_path | Two M0-following, M1-static natural-unfilled-PEEK active-sector guides | selected | rfq_ready | blocked | ready | False | False | 2 | 0 | 1 | 2 | 2 | each |  |  | {}
active-sector-aluminum-yoke | custom | machine | structure | One-solid keyed aluminum carriage yoke for the active-sector guides | selected | rfq_ready | blocked | ready | False | False | 1 | 0 | 1 | 1 | 1 | each |  |  | {}
flyer-pulley-nbk-p30-3gt-blp-6c-10 | cots | machine | motion | Stock NBK 30T 3GT backlash-less flyer pulley, 6 mm belt, D10 split-clamp bore | selected | cart_ready | blocked |  |  |  | 1 | 0 | 1 | 1 | 1 | each | NBK | P30-3GT-BLP-6C-10 | {"axial_j_kgm2":3e-06,"bore_mm":10.0,"clamp_torque_nm":0.5,"mass_g":28.0,"part_number":"P30-3GT-BLP-6C-10","source_step_sha256":"780110e1d59a988661f5ae80e9ebbe5d2eb324b9037d33a481809c939fa4c9f1","supplied_clamp_bolt":"M2"} | Confirm the current delivered price, exact-line fulfillment, and destination shipping at checkout; cart_ready is not order or motion authorization.
flyer-balance-b777-six-trim-set | custom | machine | balance | Six serialized ASTM-B777 annular flyer-balance trims: four rear stacks plus two front trims | selected | rfq_ready | blocked | ready | False | False | 6 | 0 | 1 | 6 | 6 | each |  |  | {"density_substitution_requires_new_balance_solve":true,"design_density_g_cm3":18.49,"required_records":["ASTM B777 class and lot certificate","certified density","OD, ID and axial length per serial","finished mass per serial"],"required_serial_count":6}
shaft-wrap-sleeve-default-d4 | tooling | job | wire_path | Default-job seamless polished shaft-wrap sleeve for nominal 4 mm shaft | selected | rfq_ready | order_ready |  |  |  | 1 | 1 | 1 | 2 | 2 | each |  |  | {}
default-magnet-wire-32snsp125 | consumable | job | winding_material | Remington 32SNSP.125 32 AWG single-build wire; 0.22352 mm supplier nominal finished OD; measured job input must be 0.220-0.235 mm | selected | cart_ready | order_ready |  |  |  | 1 | 0 | 1 | 1 | 1 | 2_oz_spool | Remington Industries | 32SNSP.125 | {"accepted_conservative_measured_finished_diameter_mm":{"maximum":0.235,"minimum":0.22},"default_simulation_finished_diameter_mm":0.22352,"inspection":"Accept this 50-turn job only when the conservative measured finished OD is 0.220-0.235 mm. Regenerate packing, winding plan, settings, packed routes, capture, continuous audit, and player from the measured value before hardware motion.","measurement_rule":"Measure finished OD at no fewer than five separated locations with a suitable calibrated wire micrometer and use the conservative maximum including instrument uncertainty as the job input.","regeneration_command":".venv/Scripts/python.exe cad/job_artifacts.py --wire-measured <wire_max_mm> --liner-measured <liner_max_mm>","supplier_nominal_finished_diameter_in":0.0088,"supplier_nominal_finished_diameter_mm":0.22352}
default-slot-liner-nomex410-5mil | consumable | job | winding_material | DuPont Nomex Type 410 5 mil sheet; 0.127 mm supplier nominal; measured installed job input must be 0.120-0.140 mm | selected | cart_ready | order_ready |  |  |  | 1 | 0 | 1 | 1 | 1 | sheet | BAE Wire & Insulation | INNMX410005S | {"accepted_conservative_measured_installed_thickness_mm":{"maximum":0.14,"minimum":0.12},"default_simulation_installed_thickness_mm":0.127,"inspection":"Accept this 50-turn job only when the conservative installed thickness is 0.120-0.140 mm and every core edge remains protected. Regenerate packing, winding plan, settings, packed routes, capture, continuous audit, and player before hardware motion.","measurement_rule":"Form the slot-cell process, measure installed radial thickness at no fewer than five coupon locations, and use the conservative maximum including instrument uncertainty as the job input.","regeneration_command":".venv/Scripts/python.exe cad/job_artifacts.py --wire-measured <wire_max_mm> --liner-measured <liner_max_mm>","supplier_nominal_thickness_in":0.005,"supplier_nominal_thickness_mm":0.127}
end-turn-former-default | tooling | optional | wire_path | Future optional end-turn forming tool; not part of the Goal1 flyer-winder mechanism | pending | blocked | excluded |  |  |  | 0 | 0 | 1 | 0 | 0 | each |  |  | {}
felt-backing-disc-20-4p5-1 | custom | machine | tensioner | OD20 x ID4.5 x 1 mm 304 stainless felt backing disc | selected | rfq_ready | order_ready |  |  |  | 2 | 0 | 1 | 2 | 2 | each |  |  | {}
felt-pad-20-4p5-3 | custom | machine | tensioner | OD20 x ID4.5 x 3 mm wool felt drag pad | selected | rfq_ready | order_ready |  |  |  | 2 | 4 | 1 | 6 | 6 | each |  |  | {}
felt-sheet-8341k31 | consumable | machine | tensioner | F5 plain wool felt sheet stock for locally cut drag pads | selected | cart_ready | order_ready |  |  |  | 1 | 0 | 1 | 1 | 1 | sheet | McMaster-Carr | 8341K31 | {}
dancer-standoff-sleeve-set | custom | machine | tensioner | Dancer stand-off sleeves: 2x OD5/ID3.2/L4, 1x OD4/ID2.2/L1.5, 1x OD4/ID2.2/L4 | selected | rfq_ready | order_ready |  |  |  | 4 | 0 | 1 | 4 | 4 | piece |  |  | {}
power-supply-m2-regulated-36v-condition | electronics | machine | electronics | Selected Leadshine LSP-360-36 regulated 36 VDC M2 bench/commissioning supply; mains safety integration blocked | selected | blocked | conditional |  |  |  | 1 | 0 | 1 | 1 | 1 | each | Leadshine | LSP-360-36 | {"continuous_output_current_A":10.0,"exact_model":"LSP-360-36","input_selector_must_match_site_mains_before_energizing":true,"input_voltage_windows_vac":[[92.0,138.0],[184.0,276.0]],"mains_enclosure_and_protection_release_required":true,"maximum_envelope_mm":[215.0,115.0,30.0],"output_voltage_vdc":36.0,"peak_output_current_A":18.0,"rated_power_W":360.0}
controller-board | electronics | optional | electronics | Optional controller implementation for the required serial protocol | pending | blocked | excluded |  |  |  | 1 | 0 | 1 | 1 | 1 | each |  |  | {}
structural-petg-filament | consumable | machine | print | Structural PETG filament | selected | cart_ready | order_ready |  |  |  | 1 | 0 | 1 | 1 | 1 | 1kg_spool | Micro Center | 151506 | {}
ceramic-bonding-epoxy | consumable | machine | assembly_consumable | Bonding epoxy for fixed ceramic eyelets and the interphase shaft-wrap sleeve | selected | cart_ready | order_ready |  |  |  | 1 | 0 | 1 | 1 | 1 | package | EIS | LOC21425 | {}
foot-stud-threadlocker-loctite-243 | consumable | machine | assembly_consumable | Medium-strength anaerobic threadlocker for the four foot-stack set screws | selected | cart_ready | order_ready |  |  |  | 1 | 0 | 1 | 1 | 1 | single_use_capsule | McMaster-Carr | 91458A114 | {}
hardware:91116A130 | fastener | machine | hardware | McMaster 91116A130 M4 oversized flat thrust washer | selected | cart_ready |  |  |  |  | 1 | 4 | 100 | 1 | 100 | each | McMaster-Carr | 91116A130 | {}
hardware:94125K614 | fastener | machine | hardware | McMaster 94125K614 compression spring | selected | cart_ready |  |  |  |  | 1 | 4 | 5 | 1 | 5 | each | McMaster-Carr | 94125K614 | {}
hardware:DIN315-M4 | fastener | machine | hardware | M4 wing nut | selected | cart_ready |  |  |  |  | 1 | 0 | 10 | 1 | 10 | each | McMaster-Carr | 94300A411 | {}
hardware:DIN976-M4x55 | raw_stock | machine | hardware | M4x55 fully-threaded stud | selected | cart_ready |  |  |  |  | 1 | 0 | 1 | 1 | 1 | each | McMaster-Carr | 90024A221 | {}
hardware:DIN988-3x6x0.5 | fastener | machine | hardware | OD3 DIN 988 thrust washer | selected | cart_ready |  |  |  |  | 7 | 0 | 1 | 7 | 7 | each | Accu | HSHN-3-6-0-5-A2 | {}
hardware:DIN988-5x10x0.5 | fastener | machine | hardware | OD5 DIN 988 thrust washer | selected | cart_ready |  |  |  |  | 2 | 0 | 50 | 1 | 50 | each | McMaster-Carr | 98055A098 | {}
hardware:ELESA-432001 | cots | machine | hardware | Elesa DVB.6 OD20x17 M5 rubber foot | selected | cart_ready |  |  |  |  | 4 | 0 | 1 | 4 | 4 | each | Reiman | DVB.6-20-17-M5-6-55 | {}
hardware:ISO10511-M2 | fastener | machine | hardware | M2 prevailing-torque nut | selected | cart_ready |  |  |  |  | 7 | 2 | 10 | 1 | 10 | each | McMaster-Carr | 90576A211 | {}
hardware:ISO10511-M2.5 | fastener | machine | hardware | M2.5 prevailing-torque nut | selected | cart_ready |  |  |  |  | 1 | 1 | 25 | 1 | 25 | each | McMaster-Carr | 93625A103 | {}
hardware:ISO10511-M4 | fastener | machine | hardware | M4 prevailing-torque nut | selected | cart_ready |  |  |  |  | 6 | 2 | 100 | 1 | 100 | each | McMaster-Carr | 90576A103 | {}
hardware:ISO10511-M8 | fastener | machine | hardware | M8 prevailing-torque nut | selected | cart_ready |  |  |  |  | 1 | 1 | 100 | 1 | 100 | each | McMaster-Carr | 90576A117 | {}
hardware:ISO10642-M3x6 | fastener | machine | hardware | M3x6 countersunk rear-balance screw | selected | cart_ready |  |  |  |  | 4 | 0 | 100 | 1 | 100 | each | McMaster-Carr | 92125A126 | {} | Confirm current pack price and line-specific fulfillment for this exact SKU at checkout; cart_ready is not order or motion authorization.
hardware:ISO10642-M5x12 | fastener | machine | hardware | M5x12 flush M0 bearing-support screw | selected | cart_ready |  |  |  |  | 10 | 2 | 100 | 1 | 100 | each | McMaster-Carr | 91263A833 | {}
hardware:ISO14581-M2x12 | fastener | machine | hardware | M2x12 flush fixed spring pin | selected | cart_ready |  |  |  |  | 1 | 1 | 50 | 1 | 50 | each | McMaster-Carr | 90236A107 | {}
hardware:ISO14581-M2x16 | fastener | machine | hardware | M2x16 flush moving spring pin | selected | cart_ready |  |  |  |  | 1 | 1 | 50 | 1 | 50 | each | McMaster-Carr | 90236A108 | {}
hardware:ISO4026-M3x8 | fastener | machine | hardware | M3x8 flat-point arm set screw | selected | cart_ready |  |  |  |  | 2 | 2 | 25 | 1 | 25 | each | McMaster-Carr | 92605A102 | {}
hardware:ISO4026-M5x12 | fastener | machine | hardware | M5x12 flat-point bonded foot stud | selected | cart_ready |  |  |  |  | 4 | 0 | 1 | 4 | 4 | each | Accu | SSF-M5-12-A2 | {}
hardware:ISO4032-M4 | fastener | machine | hardware | M4 jam/hex nut | selected | cart_ready |  |  |  |  | 1 | 0 | 100 | 1 | 100 | each | McMaster-Carr | 90592A011 | {}
hardware:ISO4762-M2x16 | fastener | machine | hardware | M2x16 switch screw | selected | cart_ready |  |  |  |  | 2 | 2 | 100 | 1 | 100 | each | McMaster-Carr | 91290A047 | {}
hardware:ISO4762-M2x20 | fastener | machine | hardware | M2x20 paired-cap through screw | selected | cart_ready |  |  |  |  | 3 | 0 | 100 | 1 | 100 | each | McMaster-Carr | 91290A049 | {} | Confirm current pack price and line-specific fulfillment for this exact SKU at checkout; cart_ready is not order or motion authorization.
hardware:ISO4762-M2x6 | fastener | machine | hardware | M2x6 PEEK flyer-guide screw | selected | cart_ready |  |  |  |  | 3 | 0 | 100 | 1 | 100 | each | McMaster-Carr | 91290A013 | {} | Confirm current pack price and line-specific fulfillment for this exact SKU at checkout; cart_ready is not order or motion authorization.
hardware:ISO4762-M2x8 | fastener | machine | hardware | M2x8 front-balance screw | selected | cart_ready |  |  |  |  | 2 | 0 | 100 | 1 | 100 | each | McMaster-Carr | 91290A015 | {} | Confirm current pack price and line-specific fulfillment for this exact SKU at checkout; cart_ready is not order or motion authorization.
hardware:ISO4762-M3x10 | fastener | machine | hardware | M3x10 carriage-block screw | selected | cart_ready |  |  |  |  | 22 | 4 | 100 | 1 | 100 | each | McMaster-Carr | 91502A104 | {}
hardware:ISO4762-M3x12 | fastener | machine | hardware | M3x12 T8 flange-nut screw | selected | cart_ready |  |  |  |  | 4 | 1 | 100 | 1 | 100 | each | McMaster-Carr | 91502A105 | {}
hardware:ISO4762-M3x14 | fastener | machine | hardware | M3x14 active-sector guide screw | selected | cart_ready |  |  |  |  | 4 | 0 | 100 | 1 | 100 | each | McMaster-Carr | 91502A106 | {} | Confirm current pack price and line-specific fulfillment for this exact SKU at checkout; cart_ready is not order or motion authorization.
hardware:ISO4762-M3x8 | fastener | machine | hardware | M3x8 rail screw | selected | cart_ready |  |  |  |  | 12 | 3 | 100 | 1 | 100 | each | McMaster-Carr | 91502A103 | {}
hardware:ISO4762-M4x10 | fastener | machine | hardware | M4x10 yoke-to-tower screw | selected | cart_ready |  |  |  |  | 4 | 0 | 100 | 1 | 100 | each | McMaster-Carr | 90128A212 | {} | Confirm current pack price and line-specific fulfillment for this exact SKU at checkout; cart_ready is not order or motion authorization.
hardware:ISO4762-M4x20 | fastener | machine | hardware | M4x20 front tower screw | selected | cart_ready |  |  |  |  | 2 | 2 | 100 | 1 | 100 | each | McMaster-Carr | 90128A216 | {}
hardware:ISO4762-M4x25 | fastener | machine | hardware | M4x25 rear tower/flag screw | selected | cart_ready |  |  |  |  | 4 | 2 | 100 | 1 | 100 | each | McMaster-Carr | 90128A217 | {}
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

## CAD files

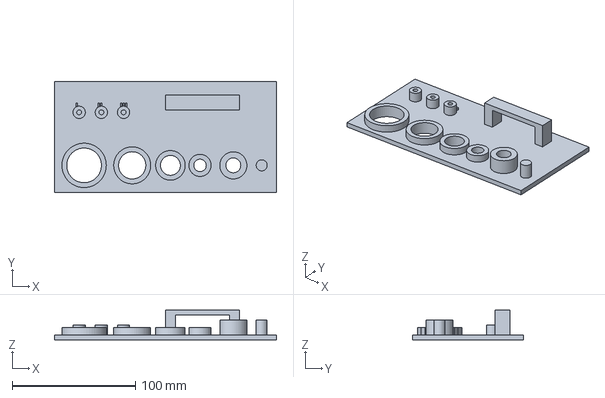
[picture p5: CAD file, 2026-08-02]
hardware/coupon/fit_bridge_coupon.step
180.0 x 90.0 x 24.0 mm

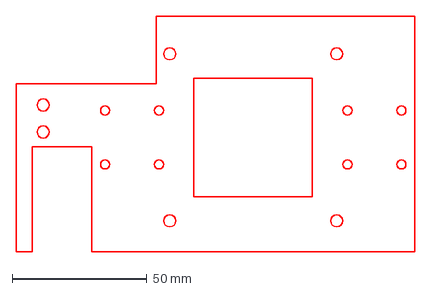
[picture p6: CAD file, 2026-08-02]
hardware/fabrication/fabricated_carriage.dxf
148.0 x 87.5 mm

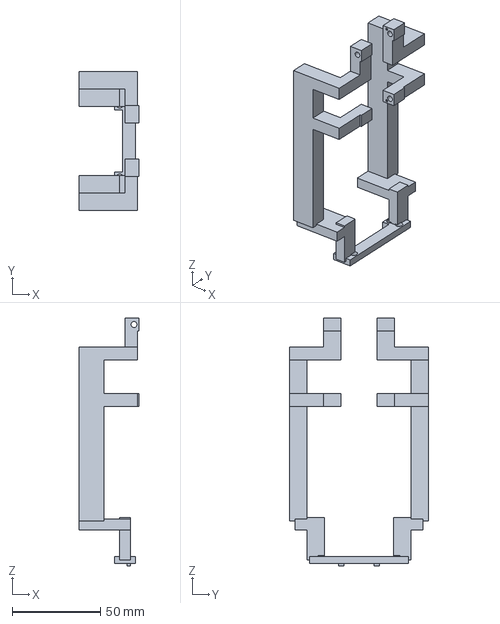
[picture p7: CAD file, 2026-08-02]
hardware/machining/successor/active_sector_aluminum_yoke.step
33.9 x 79.0 x 140.6 mm

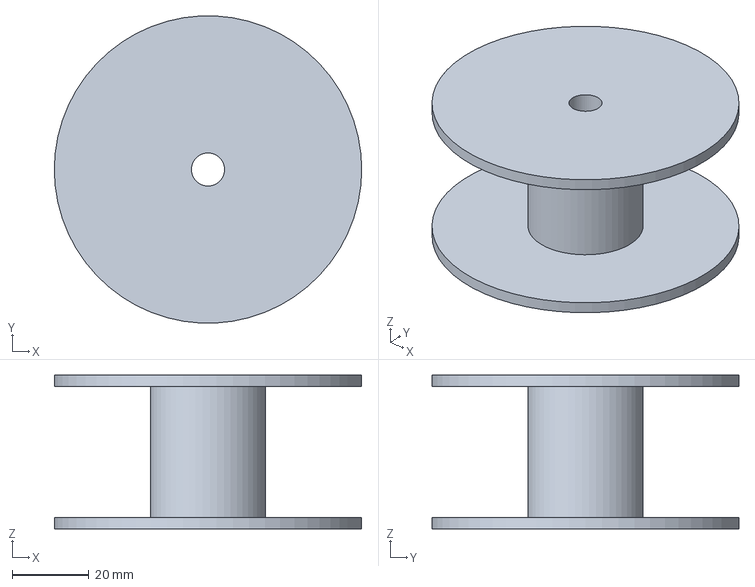
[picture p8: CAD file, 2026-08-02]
hardware/printables/step/spool_drum.step
80.0 x 79.9 x 40.0 mm

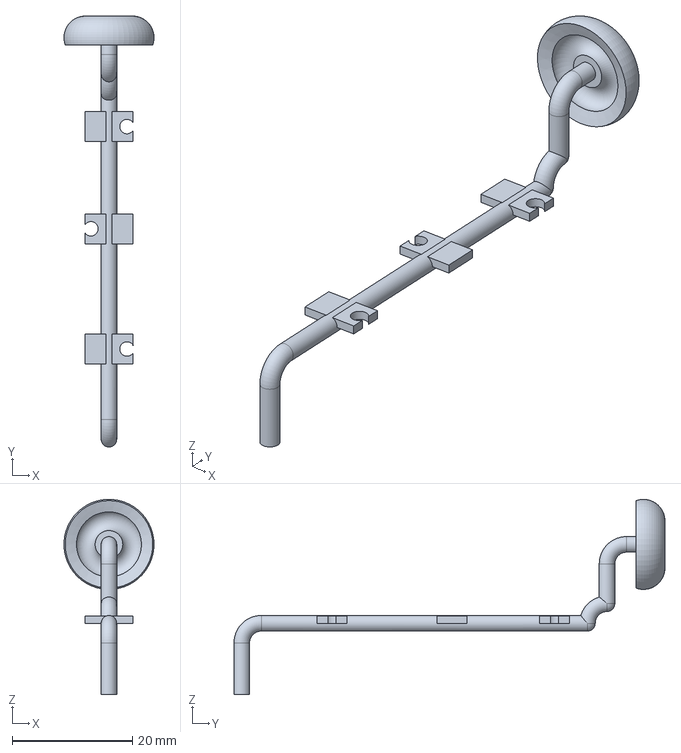
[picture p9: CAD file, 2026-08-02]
hardware/machining/successor/flyer_peek_guide_bell.step
15.0 x 71.7 x 32.5 mm

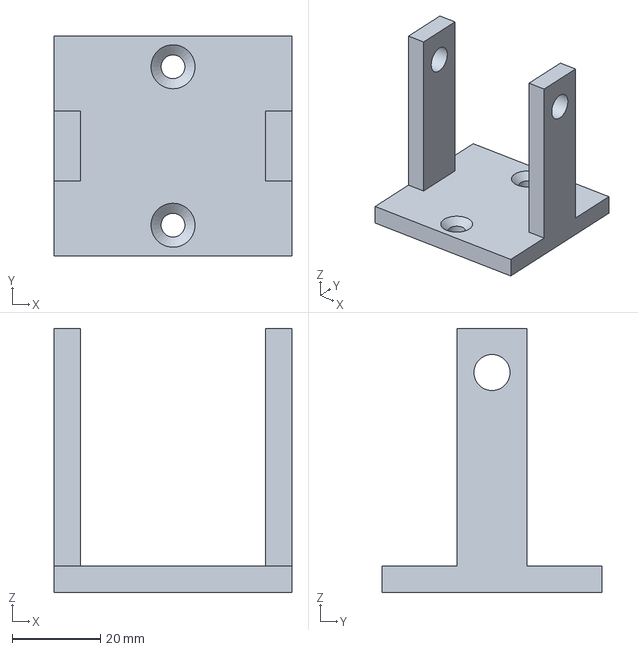
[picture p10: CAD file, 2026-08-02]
hardware/printables/step/spool_bracket.step
54.0 x 50.0 x 60.0 mm

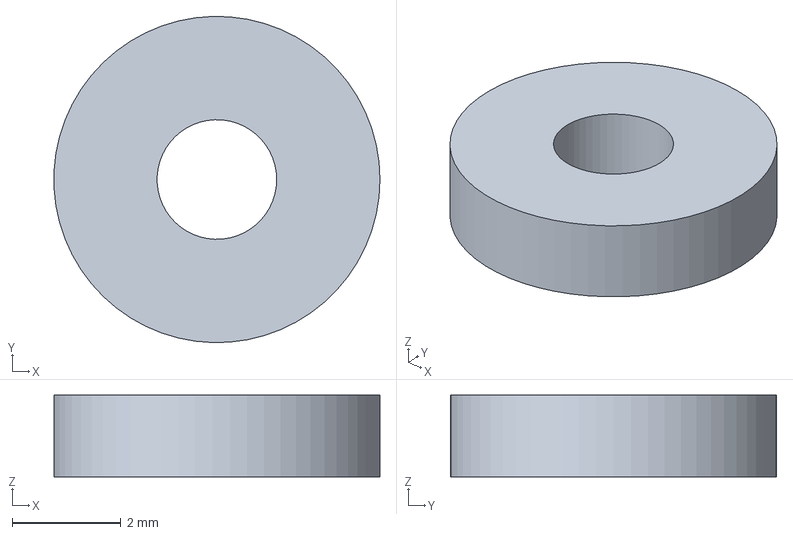
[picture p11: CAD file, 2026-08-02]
hardware/machining/successor/balance_b777_front_left.step
6.00 x 6.00 x 1.50 mm

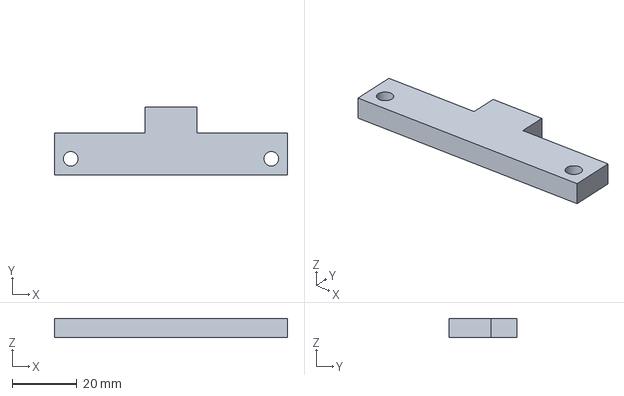
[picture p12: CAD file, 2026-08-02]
hardware/printables/step/carriage_endstop_flag.step
72.0 x 21.0 x 6.00 mm

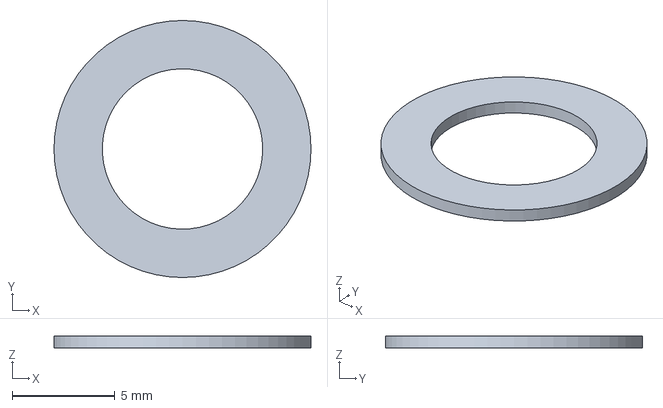
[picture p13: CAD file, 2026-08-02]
hardware/machining/successor/balance_b777_rear_2_rear_right.step
12.5 x 12.5 x 0.6 mm

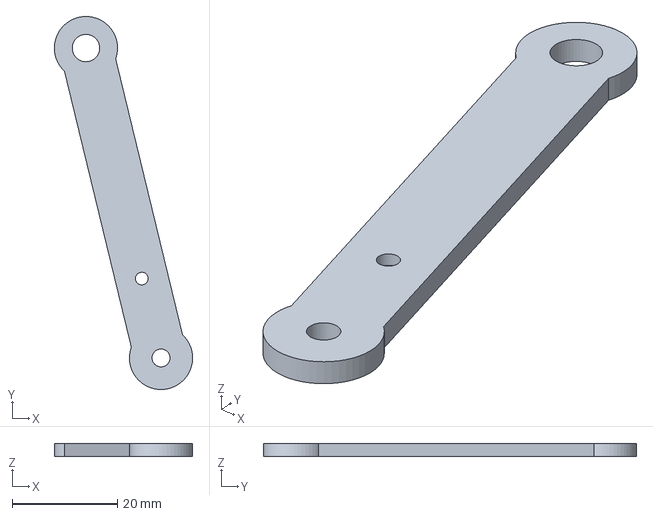
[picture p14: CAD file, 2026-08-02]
hardware/printables/step/dancer_arm.step
26.2 x 70.8 x 2.50 mm

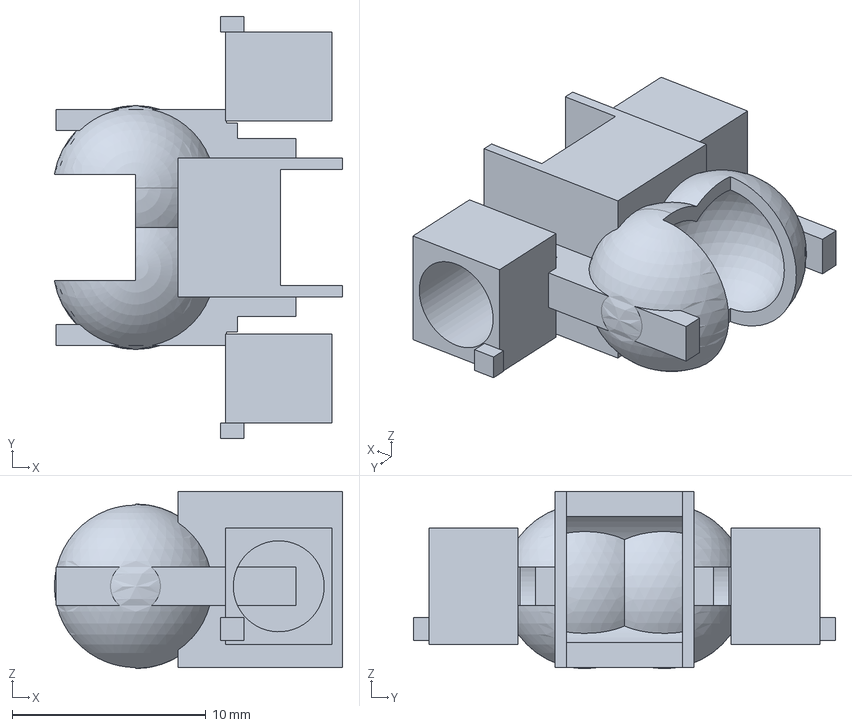
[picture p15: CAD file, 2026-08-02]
hardware/machining/successor/active_sector_peek_guide_rear.step
14.9 x 21.8 x 9.15 mm

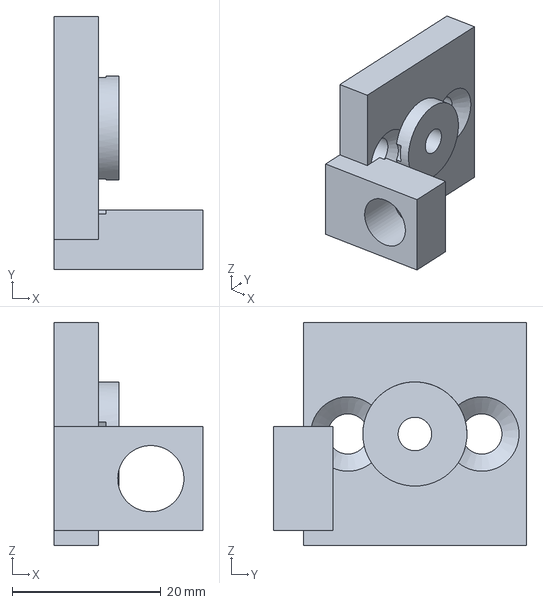
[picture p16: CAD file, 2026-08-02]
hardware/printables/step/felt_tensioner.step
20.0 x 34.0 x 30.0 mm

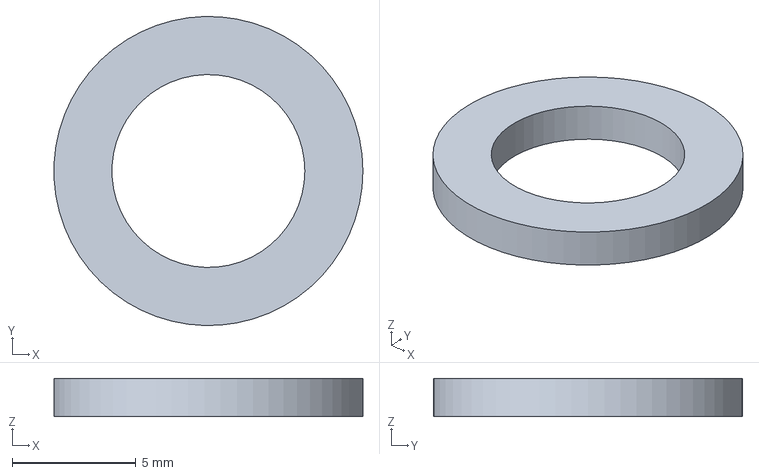
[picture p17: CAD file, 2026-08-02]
hardware/machining/successor/balance_b777_rear_1_rear_left.step
12.5 x 12.5 x 1.54 mm

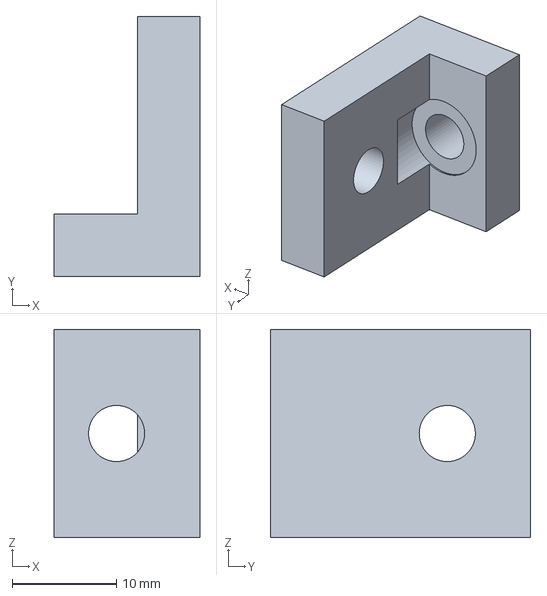
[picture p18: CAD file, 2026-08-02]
hardware/printables/step/rear_post_left_shoe.step
14.0 x 25.0 x 20.0 mm

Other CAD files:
hardware/machining/successor/balance_b777_rear_4_front_right.step
hardware/printables/step/balance_retainer_rear_right.step
hardware/machining/successor/active_sector_peek_guide_front.step
hardware/printables/step/m2_motor_mount.step
hardware/coupon/fit_bridge_coupon.3mf
hardware/coupon/fit_bridge_coupon.stl
hardware/machining/legacy/fixed_eyelet_id4_od9_t3.step
hardware/machining/legacy/flyer_shaft_d10_id6_to_id9_l79.step
hardware/machining/legacy/m0_fixed_collar.step
hardware/machining/legacy/m0_inner_shim.step
hardware/machining/legacy/m1_inner_race_spacer.step
hardware/machining/legacy/m1_lower_inner_spacer.step
hardware/machining/legacy/m1_outer_race_spacer.step
hardware/machining/legacy/m1_upper_collar.step
hardware/machining/legacy/m2_center_inner_spacer.step
hardware/machining/legacy/m2_front_inner_spacer.step
hardware/machining/legacy/m2_outer_race_spacer.step
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

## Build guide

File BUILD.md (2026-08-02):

# Builder guide

This repository now includes a loadable, project-owned mechanical package in
[`hardware/`](hardware/). It is intended to let another engineer inspect,
quote, print, and mechanically assemble the research design without receiving
supplier CAD that this project cannot redistribute.

> [!CAUTION]
> This is an alpha research build, not a production-ready or safety-qualified
> machine. The current release gates intentionally block powered winding.
> Review [`TODO.md`](TODO.md) and
> [`docs/engineering-status.md`](docs/engineering-status.md) before spending
> money or energizing hardware.

## Start here

1. Open
   [`hardware/assembly/stator_winder_reference_envelope.step`](hardware/assembly/stator_winder_reference_envelope.step)
   in FreeCAD, Fusion, Onshape, or another STEP-capable CAD system. Purchased
   components are represented by project-authored dimensional envelopes, not
   copied vendor geometry.
2. Review [`COSTS.md`](COSTS.md) and [`bom.csv`](bom.csv). The current
   `$1,573.78` subtotal is incomplete and must not be treated as a checkout
   total.
3. Print and measure the fit/bridge coupon under `hardware/coupon/` before the
   complete printed set.
4. Slice the 21 files in `hardware/printables/stl/` using the settings in
   `hardware/orders/print_jobs.csv` and the checked-in profiles under
   `print/profiles/`.
5. Use the editable versions in `hardware/printables/step/` when a printer or
   insert fit needs a controlled adjustment.
6. Send the carriage DXF, custom STEP files, and matching drawings to suitable
   fabricators for quotation. RFQ-ready does not mean order- or
   production-authorized.
7. Source purchased hardware from `hardware/orders/full_order.csv`; verify
   every current price, pack quantity, and substitution before checkout.

## Package map

```text
hardware/
  assembly/             vendor-free loadable reference assembly
  coupon/               proof coupon STEP, STL, and 3MF
  drawings/             project-authored shop/RFQ PDFs
  fabrication/          carriage DXF
  machining/legacy/     spacers, shaft, lead screw, eyelet, and holder STEP
  machining/successor/  PEEK, aluminum, and B777 successor STEP
  manifests/            checksums and external-CAD boundary
  orders/               full order, fastener, and print CSVs
  printables/step/       editable printed-part geometry
  printables/stl/        print-oriented meshes
```

## Source-only assembly generation

Python 3.11 and `requirements-dev.txt` are the verified environment. A clean
checkout can generate the public reference assembly without any supplier CAD:

```powershell
py -3.11 -m venv .venv
.venv\Scripts\python.exe -m pip install -r requirements-dev.txt
.venv\Scripts\python.exe cad\assembly.py `
  --reference-mode envelope `
  --output out\stator_winder_reference_envelope.step
```

`--reference-mode exact` is reserved for local fit and collision work after
the user has separately obtained the external models listed in
[`hardware/manifests/external-cad.json`](hardware/manifests/external-cad.json).
Exact supplier geometry is not required to open or mechanically understand
the public package.

The simpler custom machining set is also source-only:

```powershell
.venv\Scripts\python.exe cad\custom_parts.py
```

The full print and successor-manufacturing regeneration path consumes
hash-bound engineering reports from the internal validation pipeline. The
checked-in artifacts let builders inspect and quote the current geometry,
while their manifests retain the source and checksum boundary.

## Mechanical assembly order

1. Build the 2020 frame from the cut list drawing; square it before fitting
   the MGN12 rails.
2. Install the M0 screw, fixed-end bearing stack, motor, coupling, nut, and
   carriage. Confirm free travel by hand before fitting a belt or energizing a
   motor.
3. Assemble the M1 spindle tower, 608 bearing stack, selected work holder, and
   stator fixture.
4. Assemble the M2 flyer bearing stack, shaft, pulley, belt, arm, guide, and
   balance parts. Installed balance and retention tests are mandatory before
   rotation.
5. Install the spool, felt drag stack, dancer, eyelets, and wire path.
6. Verify all fastener stacks against `hardware/orders/hardware_order.csv`.
7. Stop at mechanical inspection. Controller wiring, mains enclosure,
   protective earth, emergency stop, commissioning, and powered motion remain
   separate safety work and are not authorized by this package.

## External CAD boundary

Supplier and community files were used locally to verify interfaces. They are
not necessary to load the public assembly, and they are not included when the
project does not have a clear redistribution grant. The manifest records the
expected filenames and SHA-256 values so a builder can obtain and verify their
own copies under the source's terms.

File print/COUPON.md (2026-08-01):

# PETG fit and bridge qualification coupon

Production printing is blocked until this coupon is printed with the frozen
`winder-a1-0p4-petg-strength-v1` profile and the physical checks below are
recorded as passed. The coupon is a qualification tool, not a machine part.

## Print setup

- Printer: Bambu Lab A1, 0.4 mm nozzle, Textured PEI Plate.
- Material: dry INLAND PETG Plus from the same spool intended for production.
- Process: 0.20 mm layers, 6 walls, 5 top layers, 3 bottom layers, 25% cubic
  infill, no supports.
- Use `out/print/coupon/fit_bridge_coupon.gcode`. It was sliced locally with
  OrcaSlicer 2.4.2 and has not been sent to a printer.

Regenerate the local artifact from the project-owned sources with:

```powershell
.\.venv\Scripts\python.exe print\slice_coupon.py
```

That command only invokes the local OrcaSlicer CLI; it contains no printer
discovery, upload, or start path.

## Coupon map

With the four bearing rings nearest you, read left to right:

1. 6001 bearing seat, diameter 28.1 mm.
2. 608 bearing seat, diameter 22.1 mm.
3. 688 bearing seat, diameter 16.1 mm.
4. 623 bearing seat, diameter 10.1 mm.
5. Flyer-pulley tube bore, diameter 12.05 mm.
6. Wire-elbow sleeve male gauge, diameter 8.96 mm.

The rear row has the three diameter 4.0 mm heat-set pilots. One, two, and three
tally tabs identify McMaster 94459A769 at 3.4 mm depth, 94459A130 at 4.3 mm,
and 94459A140 at 5.7 mm. The other rear feature is the exact 44 mm unsupported
spindle-pocket bridge.

## Physical acceptance record

Record actual observations; do not infer a pass from the CAD or G-code.

- Each real bearing starts square, seats with light controlled pressure without
  cracking, has no perceptible radial rock, and can be pushed back out.
- The real 12 mm OD flyer tube enters the diameter 12.05 pulley gauge without
  splitting it.
- The diameter 8.96 elbow gauge enters the real 9 mm-ID tube mouth without
  shaving material or forcing it.
- One insert of each listed SKU installs flush at its keyed depth without boss
  cracking, spin, or pullout.
- The 44 mm bridge has a continuous underside with no dropped strands. Measured
  midspan sag relative to the two ends is at most 0.50 mm.
- Record operator, date, printer, filament spool identity/dry state, measured
  bridge sag, each fit result, and any dimensional compensation applied.

Only after every item passes should `print_plan.qualification.status` become
`passed`, `production_release_allowed` become `true`, and the signed physical
record be added to the catalog.

## Production wire elbow

The released printed elbow material is PETG. Deburr and polish the complete
wire bore before use, then perform an enamel-abrasion pull test: run a sacrificial
length of the production wire through 100 reciprocating strokes under about
10 N tension and inspect under magnification. Any visible scratching, enamel
dust, or exposed copper is a failure. This test qualifies the finished elbow;
the coupon alone does not prove PETG wear life.

PTFE remains an unqualified alternative. It requires a separate machining,
retention, fit, and abrasion-validation record before substitution.

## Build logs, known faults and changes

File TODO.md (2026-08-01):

# Machine release tasks

## P0 — replace the broken presentation wire with conductor authority

Status: **OPEN — release blocker** (2026-07-12)

Selected review release: `iar1-b1e34f1942705a460d14`.  Its player fixes the
visible disconnect: every sampled cyan machine-side prefix now continues to
the ordered live deposited tail as an explicit red/dashed span.  The candidate
passed the 15 state/GLB/HTML contract tests, 26 immutable-adapter tests, and the
user's visible browser review before promotion to the canonical selector.  The
red span is presentation evidence only and does not change the physical
authority figures below.

The selected player currently joins a proven machine-side guide prefix to a
separate presentation-only workpiece tail.  The 2,400 winding loci stop at the
cap lane and leave a 0.246519–5.108399 mm cap-to-live-target gap.  Only 48
constant-route holds (1.143362928 s, 0.2145066% of the 533.02 s cycle) have
physical continuous-route authority.  The player must keep every other live
span red/dashed until the requirements below are met.

The bounded manufactured-support trade rules out seven existing fixed,
mouth-only, retained, collapsible, shrouded, and one-stage shoe families.  Its
first isolated gimbal-shoe prototype proves positive-volume R3 geometry,
6.0/1.0 mm usable radial/tangential travel, endpoint stops, four primary M4
stacks, and retained OD5/OD3 pivots.  That prototype is historical geometry
evidence only: the later all-locus placement trade proves that the current
circular nose is on the wrong absolute radial/axial datum and cannot be the
final manufactured route owner.
The exact additive-integration audit now rejects the authored keyed-tower
placement: 21 reference-pose positive-volume pairs include the current yoke,
tower, stator, cap, and guide hardware.  The follower must therefore replace
the existing active-sector yoke/guides with their U-window and explicit four-
occurrence M1/M2 owner map; it must not be merged as an additional module.
The fail-closed retraction topology now fixes the analytical datums: a
0.279--0.290 bellcrank plus independent 0.25 N return keeps the worst combined
inward load at 1.946709 N, a direct twin-roller M0 cam reaches x=14.0 mm at
axis-Z 28.633333 mm, and closed rails must hold that state through machine-Z
77 mm.  Positive gimbal docking, exact shaft/bushing/springs, dual-NC switch
hardware, CAD integration, collision/load sweeps, and fault injection remain
open; the equations alone do not authorize hardware.
The replacement layout is now constrained to one existing-corridor 6061
U-windowed carrier plus four handed moving occurrences.  The old yoke, both old
PEEK guides, their four secondary M3 stacks, duplicate tower context, central
spine, and duplicate M4 hardware must all be zero-count.  Per axial side, the
selected shoe is centered at |y|=2.05 mm and its sibling must park at
|y|=10.95 mm, exposing an 8.90 mm coarse M2-selected deployment stroke ahead
of the passive +/-0.5 mm float.
The finalized four-occurrence review STEP replaces the rejected inward
OD5x10/M4-plus-nyloc pivot stacks with complete 10 mm MISUMI SCCG5-10 grooved-
pin stacks (two DIN 988 shims and two NETWS4 retaining rings per occurrence).
At the engaged 2.05/parked 10.95 mm centres the sibling/pivot envelopes retain
3.00 mm nominal clearance; the worst passive q=-0.50 mm extreme retains
2.50 mm, a 0.50 mm reserve over the 2.00 mm requirement.  The primary mount is
four diagonal recessed NBK SSHS-M4-10-SD-ALK screws at local axes
`(29,-24.5),(35,-17.5),(29,+24.5),(35,+17.5)`, with zero washers and four
short inserts.  The manufactured-leaf audit includes the carrier, all four
15-leaf followers, all pivot hardware, and all eight primary-M4 leaves: 69
manufactured leaves plus four blocker-only selector envelopes, 73 total.  All
36 selector/gate states collapse to five exact BREP signatures with zero
positive-volume pairs.

The continuous transition audit samples 58 poses for each of four identities
(232 total) through retract, 8.90 mm selection, deploy, and both passive-float
extremes.  It finds zero positive-volume collisions, zero clearance violations,
and a 2.50 mm minimum exact non-contact clearance.  This closes sampled nominal
transition geometry only: the four coarse-selector solids are non-manufactured
blocker envelopes, and no positive selector, positive M0 retraction/interlock,
or tolerance-qualified transition exists.

The load/wear report also remains FAIL.  The high-side passive bias is
1.982709251 N, leaving only 0.017290749 N below the 2 N cap, and the conservative
local structural screen is 41.982709251 N under the bound 40 N / 5.52 N m case.
The NBK screw and igus bushing calculations are external/static screens only;
pin/ring retention, joint preload and insert behavior, carrier stress, PEEK and
anodize wear, fits, duty, fatigue, and physical proof all remain open.

The 2,400-locus, two-wire-diameter route sweep classifies all 4,800 cases, and
the rebound study constructs exact analytic C1 S-biarcs for all 4,704 nonzero
aggregate-support cases.  Neither result grants physical route authority:
zero positive-volume arcs are placed, zero cases are physically authorized,
and the circular end-arc direction is 90 degrees from the required aggregate
compression normal.  The placement trade then checks all 4,704 required arc
centres against the current replacement STEP and finds 0 covered.  This is an
absolute-datum failure, not a small clearance correction: the current nose
misses by as much as 18.112285 mm radially and 15.322574 mm axially.

The selected successor topology is four M0-owned, re-datumed XYZ flexure/slide
stages, each carrying a yaw/elevation-compliant polished C1 guide cartridge
plus mechanically separate aggregate-normal preload leaf and PEEK shoe.  An
isolated positive-volume topology prototype now exists: four identity-specific
21-leaf modules, 84 single-solid leaves total, laid out as a 2 x 2 review rack
rather than at claimed assembly positions.  Its modeled 1.50 x 2.40 x 1.10 mm
XYZ travel exceeds the exact 1.382256 x 2.233485 x 0.973370 mm common minimum;
visible +/-55 degree yaw stops and +/-10 degree elevation tabs exceed the
required half-ranges.  Each module has a polished open C1 guide cartridge, a
separate preload leaf and shoe, and an R5 floor-relief coupon targeting 2.00 mm
clearance around the conservative R3 envelope.

The hash-bound isolated audit passes all checks, and the five CAD plus two audit
tests pass (7 total).  That PASS proves only topology, positive volume, copied
identity datums/bounds, modeled motion capacity, mechanically separate preload,
and the relief target.  It does not prove a positive-volume guide surface over
all 4,704 cases, the full XYZ/yaw/elevation motion and collision envelope,
flexure or preload sizing, load/stress/fatigue/wear, finish, retention,
tolerances and fasteners, wire dynamics, buildability, carrier or machine
integration, procurement, BOM, production, or release.  Do not integrate the
current replacement carriage or isolated review rack yet.

The final placement/collision audit runs successfully and its three focused
tests pass, but its verdict is explicitly
`PASS_AUDIT__PROTOTYPE_NOT_PLACEMENT_OR_COLLISION_READY`.  All 4,704 analytic
cases fit the exact identity center bounds, modeled XYZ travel, and numeric
yaw/elevation ranges, yet the prototype Euler transform realizes the requested
guide tangent in 0/4,704 cases.  The R3 envelope remains inside the fixed R5
relief in 4,704/4,704 cases, but retains the full 2.00 mm relief margin in
0/4,704; the worst remaining margin is only 0.635960420 mm.  Direct BREP finds
12 guide-to-floor positive collisions.  Across 172 exact endpoint poses, it
also finds 34 unique self-collision pairs, eight own-floor leaf pairs, and
eight sibling pairs after exact-active-local rebasing.  The clean review-rack
sibling result therefore does not transfer to the shared carrier.

Successor v2 redesign tasks:

- Replace the current Euler-order approximation with an explicit guide frame
  that realizes every requested tangent; model a parametric elevation member
  and real yaw/elevation stops rather than static range witnesses.
- Rebuild the floor relief over the complete XYZ/orientation envelope so every
  case retains at least 2.00 mm around R3; eliminate all 12 direct guide-floor
  and eight endpoint own-floor leaf collisions.
- Repackage each module to eliminate the 34 sampled self-collision pairs over
  the full five-DOF endpoint set, then certify continuous motion between those
  endpoints rather than only 43 samples per identity.
- Design the shared active-local carrier, fastener, flexure, and sibling
  arrangement explicitly and eliminate all eight rebased sibling pairs; do not
  infer assembly clearance from the spaced 2 x 2 review rack.
- Re-run all 4,704 guide/floor cases plus continuous full-motion sweeps, then
  close flexure/preload loads, tolerance, wear, wire route/dynamics,
  buildability, assembly integration, procurement, and release gates.
The g=0 BREP audit narrows the 48 startup blockers: 24 left-side loci already
have exact +X contact on the selected PEEK floor, while all 24 right-side loci
are 0.134256245 mm from the post-cut cap, leaving a 0.022496245 mm unsupported
gap beyond the 0.111760 mm wire radius.  A constructive integral PEEK landing
can close that geometry without nominal-wire or R0.36 gauge overlap, but its
22.5 micrometre protrusion is below practical tolerance and has no force-sign,
wire-range, wear, route, or full-collision proof.  Do not clear those 24 loci by
rounding the endpoint or by treating 2D Nomex geometry as an installed BREP.
The tolerance-robust successor is an integral right-seam PEEK shelf, not that
microscopic witness: 1.50 mm radial cap-side span, 0.75 mm axial width, at least
0.30 mm backing stock, with the finished contact wall at local
Y=0.768671037 mm and a re-centered 1.00 x 0.90 x 2.40 mm seam mouth.  Exact
0.2/0.5 mm endpoint and R0.36 gauge witnesses pass with R3.5 transition runs
0.691675/1.267681 mm, but the current upstream cap groove is only 0.47752 mm
wide and therefore cannot pass 0.5 mm wire.  The full lane must be widened to
at least 0.65 mm and every 2,400 route, force-normal, balance, collision, wear,
and extraction gate re-run before this shelf can replace the 24 right-seam
blockers.
Retraction procurement is also a no-go as a stack: McMaster 5033N11 supplies
the ground OD3 shaft only after a 25-to-16 mm cut/chamfer operation, igus
WPFFM-0304-05 requires a new OD4.5/L5/flange-7.5 pocket, and neither screened
stock centering spring fits the current force/shaft/length envelope.  The
independent return must remain below 0.008326719 N/mm after its 0.25 N initial
load, which rejects the lightest screened McMaster constant-force spring; dual
Omron D4F direct-opening switches are remote-transfer candidates only because
direct actuation exceeds the follower load budget.  None are BOM/order lines.
A custom-component screen does expose two prototype paths without changing
that no-go: opposed 17-7PH torsion springs (OD4.30/ID3.70, 0.30 mm wire,
2.64 active coils, 4 mm arms) analytically deliver 0.15 N/mm each, while an
etched 17-7PH 2x(11 x 1 x 0.10 mm) fixed-guided plate is the strongest
monolithic alternative.  For the independent radial return, the otherwise
too-strong 9293K122 cartridge becomes plausible only behind an adjustable
0.235--0.315 reduction lever, individually calibrated to 0.276+/-0.010 N in a
contained service pocket.  These are screening calculations, not selected or
fatigue-qualified hardware; printed polymer is tangential-prototype-only and
is not acceptable for the continuously biased radial return.

Acceptance criteria:

- Generate one hash-bound conductor state stream from spool, felt pinch,
  dancer, hollow shaft, flyer guide, active-sector guide and cap to the live
  deposited tail for every required raw M0/M1/M2 state.
- Prove C0/C1 continuity, local centerline bend radius at least 3.0 mm, and no
  unintended rigid-edge, prior-copper, neighbor-copper or self contact.
- Certify every positive-duration transition with a swept/adaptively subdivided
  route corridor; a collection of endpoint poses alone is insufficient.
- Add real first-turn/growing-bundle support geometry if the route needs a
  physical contact owner.  Do not authorize a mathematical free-space curve as
  a manufactured wire guide.
- Make the GLB/player consume only the authoritative state stream.  Remove the
  independent diagnostic connector and bind visible authority coloring to the
  same report hash.
- Preserve fail-closed handling for load/lead capture, park, tooth/phase index,
  shaft wrap and unload/final-lead states until each has geometry and ownership.
- Re-run the full CAD/simulation suites and visible browser review; DoD 3 may
  pass only when `full_cycle_continuous_conductor_authority_audit.json` passes.

Related evidence:

- `out/reports/full_cycle_continuous_conductor_authority_audit.json`
- `out/reports/continuous_conductor_route.json`
- `out/reports/moving_half_turn_conductor_audit.json`
- `out/reports/cap_live_tail_manufactured_support_trade.json`
- `out/reports/aggregate_boundary_follower_locus_study.json`
- `out/reports/aggregate_boundary_follower_g0_normal_audit.json`
- `out/reports/aggregate_boundary_follower_g0_landing_trade.json`
- `out/reports/aggregate_boundary_follower_cad_audit.json`
- `out/reports/aggregate_boundary_follower_hardware_qualification.json`
- `out/reports/aggregate_boundary_follower_retraction_topology.json`
- `out/reports/aggregate_boundary_follower_retraction_procurement.json`
- `out/reports/aggregate_boundary_follower_custom_return_screen.json`
- `out/reports/aggregate_boundary_follower_integration_audit.json`
- `out/reports/aggregate_boundary_follower_replacement_architecture.json`
- `out/reports/aggregate_boundary_follower_replacement_cad_audit.json`
- `out/reports/aggregate_boundary_follower_replacement_transition_sweep.json`
- `out/reports/aggregate_boundary_follower_replacement_load_wear.json`
- `out/reports/aggregate_boundary_follower_route_sweep.json`
- `out/reports/aggregate_boundary_follower_c1_rebound_sweep.json`
- `out/reports/aggregate_boundary_follower_placement_trade.json`
- `cad/aggregate_boundary_follower_successor_prototype_brief.md`
- `cad/aggregate_boundary_follower_successor_prototype.py`
- `cad/aggregate_boundary_follower_successor_prototype.snapshots.json`
- `out/reports/aggregate_boundary_follower_successor_prototype_audit.json`
- `sim/aggregate_boundary_follower_successor_prototype_placement_collision_audit.py`
- `sim/test_aggregate_boundary_follower_successor_prototype_placement_collision_audit.py`
- `out/reports/aggregate_boundary_follower_successor_prototype_placement_collision_audit.json`
- `out/reports/aggregate_boundary_follower_successor_prototype_placement_collision_audit.md`
- `out/reports/aggregate_boundary_follower_acceptance.json`
- `out/review/aggregate_boundary_floating_follower.step`
- `out/review/aggregate_boundary_follower_replacement_carriage.step`
- `out/review/aggregate_boundary_follower_replacement_carriage_manifest.json`
- `out/review/aggregate_boundary_follower_successor_prototype.step`
- `out/review/aggregate_boundary_follower_successor_prototype_manifest.json`
- `out/review/snapshots/aggregate_boundary_follower_successor_iso_20260713T050344Z.png`
- `out/review/snapshots/aggregate_boundary_follower_successor_front_20260713T050344Z.png`
- `out/review/snapshots/aggregate_boundary_follower_successor_right_20260713T050344Z.png`
- `out/review/snapshots/aggregate_boundary_follower_successor_top_20260713T050344Z.png`
- `out/review/integrated_adapter/play_integrated_candidate_raw.html`

## Closed review findings

- **M2 belt/motor apparent intersection:** closed analytically.  The two pulley
  contacts are intended P30 tooth engagements; every other static and rotating
  pair clears in `out/reports/belt_audit.json`.
- **Counterweight holes over open air:** closed in CAD.  All six screws terminate
  in blind printed bosses/inserts; physical insert-fit and 20 N pull coupons
  remain open.
- **Felt tensioner visibility/contact:** closed for geometry and rendering.  Two
  separate wool-felt pads intentionally pinch the wire; drag calibration and
  abrasion remain physical checks.
- **Coil-start ambiguity:** closed in the player with explicit phase, tooth,
  direction, positioning and first-placement markers.

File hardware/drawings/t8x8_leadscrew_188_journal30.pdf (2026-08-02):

CUSTOM TR8x8(P2) LEAD SCREW - NATIVE JOURNAL | DRAWING M0-001 REV A 2026-07-10 PAGE 1/1
TR8x8(P2), 4 START, RH - 158.00 | NATIVE OD8 h9 JOURNAL - 30.00
FEATURE | NOMINAL | CONTROL
Overall length | 188.00 | +/-0.10
Thread | Tr8x8(P2), DIN 103 7e | 4-start RH; gauge to production nut
Journal | OD8 h9 x 30.00 | Ra <=0.8; axis runout <=0.03
Straightness | 188 span | <=0.10 total
Material | AISI 304 | Passivated; clean and burr-free
Ends | C0.5 max | Keep runout outside collar/bearing seat

## DO NOT SUBSTITUTE

1. The journal is retained from the original OD8 blank before
| | threading.
2. Do not cut fully threaded OD8 stock and claim the result is an
| | OD8 journal.
3. Supply material cert, inspection dimensions, and mating-nut
| | identification with quote.
UNITS: mm | UNLESS NOTED: remove burrs; break non-contact edges 0.2 max | SHAPE AUTHORITY: out/custom/step/t8x8_leadscrew_188_journal30.step

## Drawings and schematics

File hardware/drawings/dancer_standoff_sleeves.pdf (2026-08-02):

DANCER HARD-STOP AND SPRING STAND-OFF SLEEVES | DRAWING M3-LOCAL-002 REV A

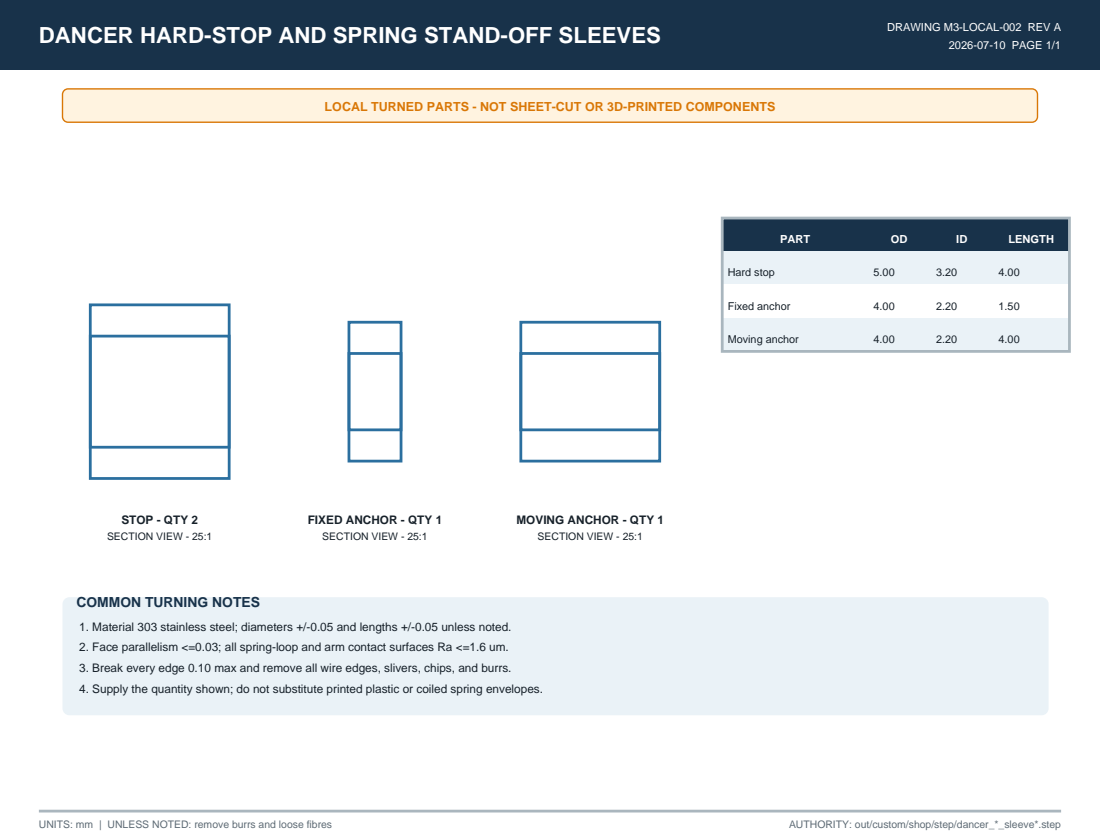
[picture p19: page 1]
2026-07-10 PAGE 1/1; STOP - QTY 2 SECTION VIEW - 25:1; PART; LENGTH; Hard stop; Fixed anchor; Moving anchor; UNITS: mm | UNLESS NOTED: remove burrs and loose fibres; AUTHORITY: out/custom/shop/step/dancer_*_sleeve*.step

LOCAL TURNED PARTS - NOT SHEET-CUT OR 3D-PRINTED COMPONENTS

FIXED ANCHOR - QTY 1
SECTION VIEW - 25:1

MOVING ANCHOR - QTY 1

COMMON TURNING NOTES
1. Material 303 stainless steel; diameters +/-0.05 and lengths +/-0.05 unless noted.
2. Face parallelism <=0.03; all spring-loop and arm contact surfaces Ra <=1.6 um.
3. Break every edge 0.10 max and remove all wire edges, slivers, chips, and burrs.
4. Supply the quantity shown; do not substitute printed plastic or coiled spring envelopes.

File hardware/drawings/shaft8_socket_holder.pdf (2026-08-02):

DEDICATED 8 MM STATOR SHAFT SOCKET HOLDER | DRAWING M1-002 REV A

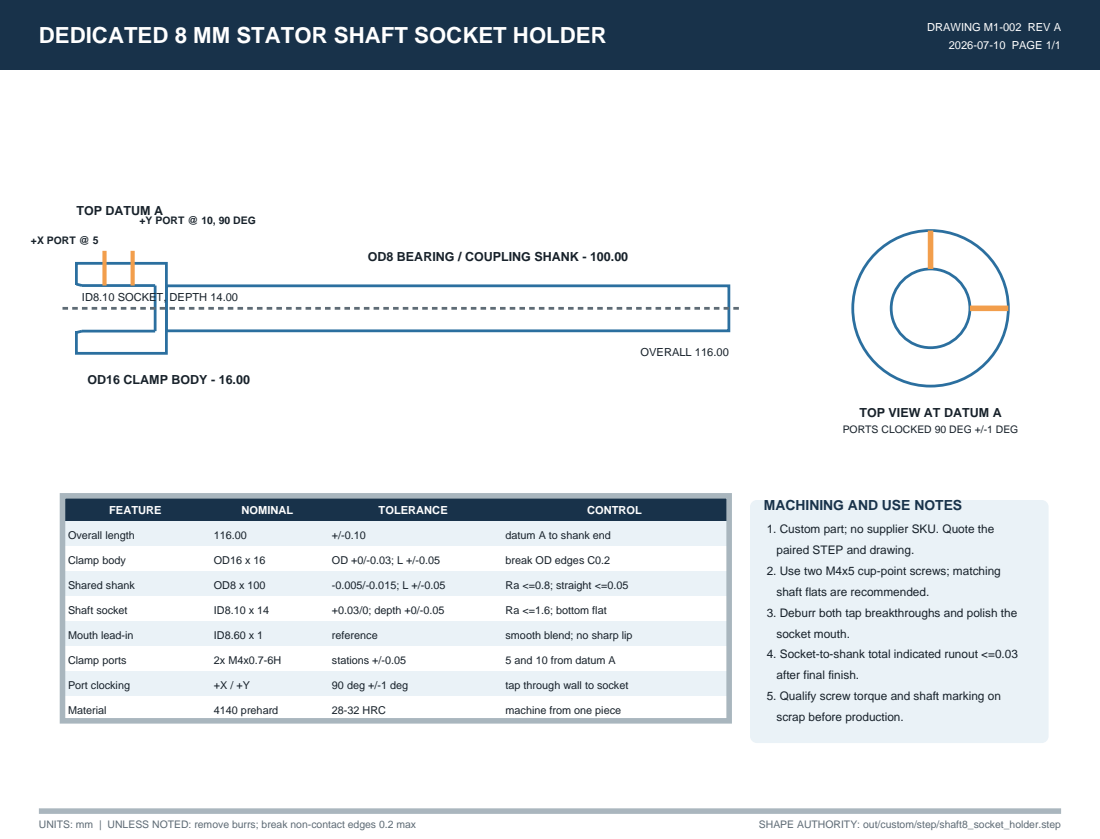
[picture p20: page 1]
2026-07-10 PAGE 1/1; +X PORT @ 5; +Y PORT @ 10, 90 DEG; TOP DATUM A; OD16 CLAMP BODY - 16.00; ID8.10 SOCKET, DEPTH 14.00; OVERALL 116.00; FEATURE; NOMINAL; TOLERANCE; CONTROL; Overall length; datum A to shank end; Clamp body; break OD edges C0.2; Shared shank; Ra <=0.8; straight <=0.05; Shaft socket; +0.03/0; depth +0/-0.05; Ra <=1.6; bottom flat; Mouth lead-in; reference; smooth blend; no sharp lip; Clamp ports; stations +/-0.05; 5 and 10 from datum A; Port clocking; 90 deg +/-1 deg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

OD8 BEARING / COUPLING SHANK - 100.00

TOP VIEW AT DATUM A
PORTS CLOCKED 90 DEG +/-1 DEG

MACHINING AND USE NOTES
1. Custom part; no supplier SKU. Quote the
paired STEP and drawing.
2. Use two M4x5 cup-point screws; matching
shaft flats are recommended.
3. Deburr both tap breakthroughs and polish the
socket mouth.
4. Socket-to-shank total indicated runout <=0.03
after final finish.
5. Qualify screw torque and shaft marking on
scrap before production.

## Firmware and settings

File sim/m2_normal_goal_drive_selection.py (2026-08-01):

"""Fail-closed normal-GOAL M2 motor and exact-1:1 drive selection.

This analysis supersedes the 17HS24 candidate as the recommended M2 motor,
but it does not authorize production.  It binds the manufacturer torque curve,
rotor inertia, exact retained flyer inertia, conservative whole-bearing and
drive-component inertia bounds, the exact 10 N / OD65 load, and the upstream
1:1 motion contract.  Pulley-to-shaft retention and installed friction remain
physical/supplier release gates.
"""

from __future__ import annotations

import hashlib
import json
import math
from pathlib import Path


ROOT = Path(__file__).resolve().parent.parent
REPORTS = ROOT / "out" / "reports"
RETAINED_REPORT = REPORTS / "permanent_cap_offset_spoke_retained_review.json"
OUTPUT_JSON = REPORTS / "m2_normal_goal_drive_selection.json"
OUTPUT_MD = REPORTS / "m2_normal_goal_drive_selection.md"

CAD_UPGRADES = ROOT / "cad" / "models" / "upgrades"
LEADSHINE_STEP = CAD_UPGRADES / "CS-M21708.STEP"
LEADSHINE_2D = CAD_UPGRADES / "Leadshine_CS-M21708_2D.pdf"
LEADSHINE_CURVE = CAD_UPGRADES / "Leadshine_CS-M21708_torque_curve.png"
LEADSHINE_CABLELESS = CAD_UPGRADES / "CS-M21708_cableless.step"
LEADSHINE_DRIVER_MANUAL = (
    CAD_UPGRADES / "Leadshine_CS-D508_manual_v1.0.pdf"
)
NBK_SLIP_CHART = CAD_UPGRADES / "NBK_aluminum_set_screw_slip_torque_reference.jpg"

LEADSHINE_PRODUCT_URL = (
    "https://www.leadshine.com/product-detail/closed-loop-stepper-drive/"
    "closed-loop-stepper/CS-M21708.html"
)
LEADSHINE_3D_URL = (
    "https://www.leadshine.com/upfiles/downloads/"
    "3c4df9dc7e3237fbdafee94f4142513a_1651890419697.zip"
)
LEADSHINE_2D_URL = (
    "https://www.leadshine.com/upfiles/downloads/"
    "fd433814f61a6818f9141c1952fc33eb_1651890544432.pdf"
)
LEADSHINE_DRIVER_URL = (
    "https://www.leadshine.com/product-detail/CS-D508.html"
)
LEADSHINE_DRIVER_MANUAL_URL = (
    "https://www.leadshine.com/upfiles/downloads/"
    "6a05fc89c7f263374eafe258220c3463_1665569910600.pdf"
)
LEADSHINE_DRIVER_SOFTWARE_MANUAL_URL = (
    "https://www.leadshine.com/upfiles/downloads/"
    "14419125f0bab74945cb1577be162c56_1665570154673.pdf"
)
LEADSHINE_CURRENT_STEPPER_CATALOG_URL = (
    "https://www.leadshine.com/upfiles/downloads/"
    "9d1b16bdd74302c1d533074657f1b972_1743650341386.pdf"
)
LEADSHINE_36V_PSU_URL = (
    "https://www.leadshine.com/product-detail/LSP-360-36.html"
)
NBK_P30_URL = (
    "https://www.nbk1560.com/products/pulley/timingpulley/"
    "3GT-BLP-6C/P30-3GT-BLP-6C/"
)
NBK_D_SHAFT_GUIDANCE_URL = (
    "https://www.nbk1560.com/images/en-US/product/contents/"
    "toritsuke_coupling_NBK/toritsuke_coupling_NBK_1.pdf"
)
NBK_SLIP_TORQUE_URL = (
    "https://www.nbk1560.com/en-US/resources/coupling/article/"
    "couplicon-set-screw-type-slip-torque/?SelectedLanguage=en-US"
)
NBK_CAD_GUIDE_URL = "https://www.nbk1560.com/en-US/guide/cad/"
NBK_CAD_REQUEST_URL = (
    "https://www.nbk1560.com/en/contact/cadrequest/?SelectedLanguage=en"
)
NBK_BELT_URL = "https://www.nbk1560.com/products/pulley/timingpulley_option/3GT-6/"
SKF_6001_URL = "https://www.emarketplace.in.skf.com/deep-groove-ball-bearing/6001-2z"

EXPECTED_SOURCE_HASHES = {
    "cad/models/upgrades/CS-M21708.STEP": (
        "7e995e724fc7e019278e0a919ba1db8c8abb3333f156c64eb6e62485e0f6662b"
    ),
    "cad/models/upgrades/Leadshine_CS-M21708_2D.pdf": (
        "b0edb4d9486562f2ead76c1363ac78ee4c20d3abaa3ad5a93eab60eb83a81141"
    ),
    "cad/models/upgrades/Leadshine_CS-M21708_torque_curve.png": (
        "00b7382799799a7a233abac07e3fd2a3dc77dca3a19c0b29dda72f9fa3c938cf"
    ),
    "cad/models/upgrades/Leadshine_CS-D508_manual_v1.0.pdf": (
        "0faaf40eebe24203511b50b3e3658bec9fc298b13221031759b84d3eb9bdba60"
    ),
    "cad/models/upgrades/NBK_aluminum_set_screw_slip_torque_reference.jpg": (
        "70cae21dcd074ed35dc534fffafc9787f3a02f2c2236f408375447568250222e"
    ),
}

# Frozen normal-GOAL duty.
FLYER_RPM = 300.0
WIRE_TENSION_N = 10.0
LINE_OF_ACTION_MM = 32.5
WIRE_TORQUE_NM = WIRE_TENSION_N * LINE_OF_ACTION_MM / 1000.0
FRICTION_ALLOWANCE_NM = 0.020
ANGULAR_ACCELERATION_RAD_S2 = 200.0
REQUIRED_TORQUE_MULTIPLE = 2.0

# Leadshine product and plot data.  The 0.735 value is one pixel below the
# lower red-curve edge at 300 RPM, not the curve center (~0.741 N m).
LEADSHINE_MODEL = "CS-M21708"
LEADSHINE_ROTOR_INERTIA_KGM2 = 0.11e-4  # 0.11 kg cm^2
LEADSHINE_36V_300RPM_LOWER_EDGE_NM = 0.735
LEADSHINE_24V_300RPM_LOWER_EDGE_NM = 0.722
LEADSHINE_CURVE_RMS_A = 2.5
LEADSHINE_CURVE_EQUIVALENT_PEAK_A = LEADSHINE_CURVE_RMS_A * math.sqrt(2.0)
LEADSHINE_DRIVER_CURRENT_INCREMENT_A_PEAK = 0.1
LEADSHINE_DRIVER_NEAREST_PEAK_SETTINGS_A = (3.5, 3.6)
LEADSHINE_SUPPLY_MODEL = "LSP-360-36"
LEADSHINE_SUPPLY_OUTPUT_VDC = 36.0
LEADSHINE_SUPPLY_CONTINUOUS_A = 10.0
LEADSHINE_SUPPLY_PEAK_A = 18.0
LEADSHINE_SUPPLY_POWER_W = 360.0
LEADSHINE_SUPPLY_INPUT_WINDOWS_VAC = ((92.0, 138.0), (184.0, 276.0))
LEADSHINE_SUPPLY_SIZE_MM = (215.0, 115.0, 30.0)
LEADSHINE_SUPPLY_OFFICIAL_PRICE_USD = 199.0
LEADSHINE_DRIVER_CONDITION = (
    "36 VDC, RMS 2.5 A motor-curve condition; Leadshine CS-D508 is the "
    "selected officially tested-compatible 20-50 VDC / 8.0 A-peak driver, "
    "but its 0.1 A peak increments cannot encode the exact 3.5355 A curve "
    "equivalent, so 3.5 A versus 3.6 A remains a production proof gate"
)

NBK_P30_D5_STOCK_STEP = (
    CAD_UPGRADES / "NBK_P30-3GT-BLP-6C-5_AP214.step"
)
NBK_P30_D5_STOCK_STEP_SHA256 = (
    "996449b7d9ec7703e7b38c6f75eff00a1174e3e1f088c05f0f1460b205169df9"
)

# Exact/reference drive inertia at 1:1.
FLYER_P30_AND_TWO_SCREWS_INERTIA_KGM2 = 2.61871821045676e-6
MOTOR_P30_PUBLISHED_INERTIA_KGM2 = 3.0e-6
MOTOR_PULLEY_M2_WITNESS_INERTIA_KGM2 = 6.8252109555268e-9
# The BNW product-specific set-screw size/length is not exposed before the
# generated drawing/quote.  Bound its acceleration load with two much larger
# M3x12 steel radial screws, spanning radius 2.5..14.5 mm (including 3 mm proud
# of the published E23 clamp envelope).  This is an inertia bound only; it does
# not assert that M3x12 is the delivered BNW hardware or prove slip torque.
BNW_SET_SCREW_COUNT = 2
BNW_INERTIA_BOUND_DIAMETER_M = 0.003
BNW_INERTIA_BOUND_LENGTH_M = 0.012
BNW_INERTIA_BOUND_STEEL_DENSITY_KG_M3 = 7850.0
BNW_INERTIA_BOUND_R0_M = 0.0025
BNW_INERTIA_BOUND_R1_M = 0.0145
ONE_BNW_INERTIA_BOUND_SCREW_MASS_KG = (
    BNW_INERTIA_BOUND_STEEL_DENSITY_KG_M3
    * math.pi
    * (BNW_INERTIA_BOUND_DIAMETER_M / 2.0) ** 2
    * BNW_INERTIA_BOUND_LENGTH_M
)
ONE_BNW_INERTIA_BOUND_SCREW_KGM2 = ONE_BNW_INERTIA_BOUND_SCREW_MASS_KG * (
    (
        BNW_INERTIA_BOUND_R0_M**2
        + BNW_INERTIA_BOUND_R0_M * BNW_INERTIA_BOUND_R1_M
        + BNW_INERTIA_BOUND_R1_M**2
    )
    / 3.0
    + (BNW_INERTIA_BOUND_DIAMETER_M / 2.0) ** 2 / 4.0
)
MOTOR_P30_SPLIT_CLAMP_BNW_INERTIA_UPPER_KGM2 = (
    MOTOR_P30_PUBLISHED_INERTIA_KGM2
    + MOTOR_PULLEY_M2_WITNESS_INERTIA_KGM2
    + BNW_SET_SCREW_COUNT * ONE_BNW_INERTIA_BOUND_SCREW_KGM2
)
BELT_MASS_KG = 0.0032
PITCH_MM = 3.0
PULLEY_TEETH = 30
PITCH_RADIUS_M = (PULLEY_TEETH * PITCH_MM / math.pi) / 2.0 / 1000.0
BELT_INERTIA_KGM2 = BELT_MASS_KG * PITCH_RADIUS_M**2

# Two 6001 bearings, conservatively treating each complete 22 g bearing as a
# rotating annulus between its 12 mm bore and 28 mm OD.
BEARING_COUNT = 2
BEARING_MASS_KG_UPPER = 0.022
BEARING_INNER_RADIUS_M = 0.006
BEARING_OUTER_RADIUS_M = 0.014
ONE_WHOLE_BEARING_INERTIA_KGM2 = 0.5 * BEARING_MASS_KG_UPPER * (
    BEARING_INNER_RADIUS_M**2 + BEARING_OUTER_RADIUS_M**2
)
BEARING_INERTIA_UPPER_KGM2 = BEARING_COUNT * ONE_WHOLE_BEARING_INERTIA_KGM2

# Official 36 V red-curve conservative readings for the requested exploratory
# ratio sweep.  These are lower edges (plus one pixel), not centerline values.
RATIO_CURVE_LOWER_EDGE_NM = {
    1.00: 0.735,
    1.10: 0.722,
    1.25: 0.710,
    1.50: 0.673,
    2.00: 0.592,
    2.50: 0.539,
    3.00: 0.486,
}

LEGACY_ROTATING_ROWS = (
    "shifted_flyer_pulley_exact_1_to_1",
    "flyer_pulley_radial_M3x8_set_screw",
    "flyer_pulley_radial_M3_short_insert",
)


def _sha256(path: Path) -> str:
    return hashlib.sha256(path.read_bytes()).hexdigest()


def _retained_inertia() -> tuple[float, float, dict[str, float]]:
    report = json.loads(RETAINED_REPORT.read_text(encoding="utf-8"))
    total = report["exact_rotating_mass_properties"]["izz_about_M2_axis_kg_m2"]
    rows = {
        row["name"]: row["izz_about_M2_axis_g_mm2"] * 1.0e-9
        for row in report["exact_rotating_mass_rows"]
    }
    missing = set(LEGACY_ROTATING_ROWS) - set(rows)
    if missing:
        raise RuntimeError(f"retained report missing legacy drive rows: {sorted(missing)}")
    removed = {name: rows[name] for name in LEGACY_ROTATING_ROWS}
    base_without_legacy_drive = total - sum(removed.values())
    return total, base_without_legacy_drive, removed


def _ratio_trade(base_without_legacy_drive: float) -> list[dict]:
    rows = []
    motor_pitch_diameter_mm = PULLEY_TEETH * PITCH_MM / math.pi
    for ratio, motor_torque_nm in RATIO_CURVE_LOWER_EDGE_NM.items():
        flyer_pitch_diameter_mm = motor_pitch_diameter_mm * ratio
        belt_pitch_length_mm = (
            2.0 * 60.0
            + math.pi / 2.0 * (motor_pitch_diameter_mm + flyer_pitch_diameter_mm)
            + (flyer_pitch_diameter_mm - motor_pitch_diameter_mm) ** 2
            / (4.0 * 60.0)
        )
        belt_mass_kg = BELT_MASS_KG * belt_pitch_length_mm / 210.0
        belt_output_inertia = belt_mass_kg * (
            flyer_pitch_diameter_mm / 2.0 / 1000.0
        ) ** 2
        # Conservative similar-radial-geometry scaling: mass ~r^2 and J~r^4.
        flyer_pulley_output_inertia = (
            FLYER_P30_AND_TWO_SCREWS_INERTIA_KGM2 * ratio**4
        )
        motor_side_reflected = (
            LEADSHINE_ROTOR_INERTIA_KGM2
            + MOTOR_P30_SPLIT_CLAMP_BNW_INERTIA_UPPER_KGM2
        ) * ratio**2
        full_output_inertia = (
            base_without_legacy_drive
            + BEARING_INERTIA_UPPER_KGM2
            + flyer_pulley_output_inertia
            + belt_output_inertia
            + motor_side_reflected
        )
        required_output_torque = (
            WIRE_TORQUE_NM
            + FRICTION_ALLOWANCE_NM
            + ANGULAR_ACCELERATION_RAD_S2 * full_output_inertia
        )
        available_output_torque = ratio * motor_torque_nm
        rows.append(
            {
                "ratio_motor_speed_over_flyer_speed": ratio,
                "motor_rpm_at_300_flyer_rpm": ratio * FLYER_RPM,
                "digitized_36V_motor_torque_lower_edge_nm": motor_torque_nm,
                "ideal_available_output_torque_nm": available_output_torque,
                "approximate_belt_pitch_length_mm": belt_pitch_length_mm,
                "full_output_inertia_kgm2": full_output_inertia,
                "required_output_torque_nm": required_output_torque,
                "available_to_required_multiple": (
                    available_output_torque / required_output_torque
                ),
                "motor_math_ge_2x": (
                    available_output_torque
                    >= REQUIRED_TORQUE_MULTIPLE * required_output_torque
                ),
            }
        )
    return rows


def analyze() -> dict:
    source_hashes = {
        str(path.relative_to(ROOT)).replace("\\", "/"): _sha256(path)
        for path in (
            LEADSHINE_STEP,
            LEADSHINE_2D,
            LEADSHINE_CURVE,
            LEADSHINE_DRIVER_MANUAL,
            NBK_SLIP_CHART,
        )
    }
    if source_hashes != EXPECTED_SOURCE_HASHES:
        raise RuntimeError("Leadshine source artifacts no longer match the reviewed files")

    retained_total, retained_base, removed = _retained_inertia()
    full_inertia = sum(
        (
            retained_base,
            FLYER_P30_AND_TWO_SCREWS_INERTIA_KGM2,
            MOTOR_P30_SPLIT_CLAMP_BNW_INERTIA_UPPER_KGM2,
            BELT_INERTIA_KGM2,
            LEADSHINE_ROTOR_INERTIA_KGM2,
            BEARING_INERTIA_UPPER_KGM2,
        )
    )
    acceleration_torque = ANGULAR_ACCELERATION_RAD_S2 * full_inertia
    required_torque = WIRE_TORQUE_NM + FRICTION_ALLOWANCE_NM + acceleration_torque
    two_x_threshold = REQUIRED_TORQUE_MULTIPLE * required_torque
    motor_multiple = LEADSHINE_36V_300RPM_LOWER_EDGE_NM / required_torque
    motor_gate = LEADSHINE_36V_300RPM_LOWER_EDGE_NM >= two_x_threshold
    at_24v_multiple = LEADSHINE_24V_300RPM_LOWER_EDGE_NM / required_torque

    pulley_allowable_nm = 2.06 * 0.9 * 1.0
    pulley_capacity_gate = pulley_allowable_nm >= two_x_threshold

    dual_inertia = (
        retained_base
        + BEARING_INERTIA_UPPER_KGM2
        + 2.0
        * (
            FLYER_P30_AND_TWO_SCREWS_INERTIA_KGM2
            + BELT_INERTIA_KGM2
            + MOTOR_P30_SPLIT_CLAMP_BNW_INERTIA_UPPER_KGM2
            + 9.0e-6
        )
    )
    dual_required = (
        WIRE_TORQUE_NM
        + FRICTION_ALLOWANCE_NM
        + ANGULAR_ACCELERATION_RAD_S2 * dual_inertia
    )
    dual_available = 2.0 * 0.430
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

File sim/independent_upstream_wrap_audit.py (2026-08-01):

"""Independent fail-closed audit of untouched-upstream M1 shaft wraps.

This audit consumes the real ``capture.py --controller upstream`` event stream.
It does not import, monkeypatch, or edit the upstream ``winder`` checkout.  Its
job is narrower than the project cycle verifier: determine whether settings or
an affine fixed mechanical transmission can turn both raw inter-phase moves
into exactly two physical chuck revolutions while preserving completed targets.
"""

from __future__ import annotations

import argparse
import hashlib
import itertools
import json
import math
import subprocess
from pathlib import Path
from typing import Any

import yaml

from traj import Timeline, load_events


HERE = Path(__file__).resolve().parent
MACHINE = HERE.parent
ROOT = MACHINE.parent
DEFAULT_CAPTURE = MACHINE / "out" / "capture" / \
    "independent_upstream_wrap_6039.jsonl"
DEFAULT_SETTINGS = MACHINE / "out" / "settings.yml"
DEFAULT_WINDER = ROOT / "winder"
DEFAULT_JSON = MACHINE / "out" / "reports" / \
    "independent_upstream_wrap_audit.json"
DEFAULT_MD = MACHINE / "out" / "reports" / \
    "independent_upstream_wrap_audit.md"
EXPECTED_COMMIT = "6039b33c8f15a20086c2195c3f2d02b3a833e8ca"
CANONICAL = "AaAabBbBCcCcaAaABbBbcCcC"
PHASES = "abc"


def _sha256(path: Path) -> str:
    return hashlib.sha256(path.read_bytes()).hexdigest()


def _git(winder: Path, *args: str) -> str:
    return subprocess.check_output(
        ["git", "-C", str(winder), *args], text=True
    ).strip()


def _source_line(lines: list[str], needle: str) -> int:
    return next(index for index, line in enumerate(lines, 1) if needle in line)


def _phase_indices(config: str) -> dict[str, list[int]]:
    lowered = config.lower()
    return {
        phase: [index for index, char in enumerate(lowered) if char == phase]
        for phase in PHASES
    }


def _canonical_equivalents(config: str) -> set[str]:
    """All rotation/reflection/polarity/phase-name equivalents."""
    variants: set[str] = set()
    for reflected in (False, True):
        base = config[::-1] if reflected else config
        for inverted in (False, True):
            polarized = base.swapcase() if inverted else base
            for offset in range(len(config)):
                rotated = polarized[offset:] + polarized[:offset]
                for permutation in itertools.permutations(PHASES):
                    rename = dict(zip(PHASES, permutation))
                    variants.add("".join(
                        rename[char.lower()].upper()
                        if char.isupper() else rename[char]
                        for char in rotated
                    ))
    return variants


def _requested_turns(config: str) -> tuple[float, float]:
    groups = _phase_indices(config)
    if any(len(groups[phase]) != 8 for phase in PHASES):
        raise ValueError("a 24-slot three-phase job must contain 8 A/B/C teeth")
    result = []
    for previous, following in (("a", "b"), ("b", "c")):
        last_index = groups[previous][-1]
        first_index = groups[following][0]
        clockwise = config[first_index].islower()
        result.append(
            2.0 - last_index / 24.0
            if clockwise else 2.0 + last_index / 24.0
        )
    return result[0], result[1]


def _wrap_rows(events: list[dict[str, Any]], timeline: Timeline) \
        -> list[dict[str, Any]]:
    calls = [event for event in events
             if event.get("e") == "wind_wire_around_shaft"]
    rows: list[dict[str, Any]] = []
    velocity = float(timeline.meta["velocities"][1])
    for ordinal, call in enumerate(calls, 1):
        start_t = float(call["t"])
        m1_command = next(
            event for event in events
            if event.get("e") == "cmd" and event.get("m") == 1
            and float(event["t"]) >= start_t - 1.0e-12
        )
        m2_return = next(
            event for event in events
            if event.get("e") == "cmd" and event.get("m") == 2
            and float(event["t"]) > start_t + 1.0e-12
        )
        method_done = next(
            event for event in events
            if event.get("e") == "wind_wire_around_shaft_done"
            and float(event["t"]) > start_t
        )
        next_m1 = next(
            event for event in events
            if event.get("e") == "cmd" and event.get("m") == 1
            and float(event["t"]) > start_t + 1.0e-12
        )
        start_m1 = float(timeline.axes[1].pos_at(start_t))
        target_m1 = float(m1_command["model_target"])
        delta = target_m1 - start_m1
        arrival_t = start_t + abs(delta) / velocity
        m2_return_t = float(m2_return["t"])
        next_m1_t = float(next_m1["t"])
        turns = abs(delta) / (2.0 * math.pi)
        rows.append({
            "index": ordinal,
            "next_wire_index": int(call["args"][0]),
            "start_t_s": start_t,
            "m1_start_rad": start_m1,
            "m1_absolute_target_rad": target_m1,
            "serial_command": m1_command["command"].rstrip("\n"),
            "controller_target_rad": float(m1_command["controller_target"]),
            "m1_delta_rad": delta,
            "completed_motor_turns": turns,
            "exactly_two_turns": math.isclose(turns, 2.0, abs_tol=1.0e-9),
            "predicted_arrival_t_s": arrival_t,
            "m2_recenter_command_t_s": m2_return_t,
            "method_done_t_s": float(method_done["t"]),
            "next_m1_target_t_s": next_m1_t,
            "arrival_slack_before_m2_recenter_s": m2_return_t - arrival_t,
            "arrival_slack_before_next_m1_target_s": next_m1_t - arrival_t,
            "target_complete_before_m2_recenter": arrival_t <= m2_return_t,
            "target_complete_before_next_m1_target": arrival_t <= next_m1_t,
            "m1_at_target_at_m2_recenter_rad": float(
                timeline.axes[1].pos_at(m2_return_t)),
            "next_m1_serial_command": next_m1["command"].rstrip("\n"),
        })
    return rows
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

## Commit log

2026-08-01 Publish stator winder source
    Create a clean open-source snapshot with project-owned source, explicit provenance and license boundaries, and an animated simulation preview.
    [bom.csv]
2026-08-02 Add alpha hardware build package
    [active_sector_aluminum_yoke.step, active_sector_peek_guide_front.step, active_sector_peek_guide_rear.step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]
